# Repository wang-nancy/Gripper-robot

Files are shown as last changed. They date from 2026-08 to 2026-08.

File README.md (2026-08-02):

# 5-Jaw Radial Gripper — FEA (Ansys)

Static structural analysis of a 5-jaw radial gripper with central pushrod
(slider-crank) actuation, in Ansys Mechanical 2026 R1. This is an in-progress
study — preliminary results are reported below with their known limitations, and
the full write-up is in [`FEA-process-documentation.md`](FEA-process-documentation.md).

## The mechanism

Five jaws spaced at 72° are driven by a central pushrod through five crank links:
the pushrod moves axially and each crank rotates its jaw inward (closing) or
outward (opening) — a slider-crank. Roughly 150 mm from mounting flange to jaw tip,
with ~34 mm of pushrod travel between fully open and fully closed.

## Load case & mechanical advantage (from first principles)

No load spec existed, so one was built from the payload. For a 5 kg object held by
friction across 5 jaws, with a 3.0 safety factor and a 0.30 friction coefficient, the
required grip force per jaw is:

```
F_grip = (m · g · SF) / (μ · n)
       = (5 · 9.81 · 3.0) / (0.30 · 5)
       ≈ 98 N per jaw
```

Because the gripper is a slider-crank, the pushrod force needed to hold a given grip
force isn't constant across the stroke. Mechanical advantage is worst at the **fully
open** position, where the crank link sits perpendicular (90°) to the pushrod axis — so
it takes the most pushrod force there to resist a given jaw load. That's the worst-case
actuation point, and the position an actuator-sizing calculation should be run against.

To map this across the full stroke, an interactive linkage force calculator was built
from the linkage geometry (crank ~20 mm pin-to-pin, jaw pivot-to-link-pin ~14 mm, jaw
pivot-to-tip ~38 mm) to estimate mechanical advantage at each position and locate that
worst case. These dimensions are current estimates from a reference model and should be
replaced with exact CAD measurements before the numbers are treated as final.

The FEA itself was run at **50 N per jaw** as an initial test value (below the 98 N
target), applied radially outward at each jaw tip to represent the gripped object
pushing back. Fixed support on the mounting flange.

## Modeling approach & key decisions

- **Transient → Static Structural.** A locked-pushrod grip check has no meaningful
  inertia or time dependence, so the transient formulation was dropped in favor of
  static — faster and better-conditioned.
- **Two-step loading.** Step 1 closes the mechanism through its full stroke with
  forces off; step 2 applies the grip load with the linkage locked closed. Ramping
  displacement and force together (the original single-step setup) let the jaws swing
  open under load before the linkage engaged — the source of the unrealistic early
  deflection. Separating the two fixed it.
- **Convergence handling.** The solver's reference value was dropping near zero, so a
  minimum force-convergence reference of 50 N was set; large deflection kept on for
  the rotating linkage.

## Results (static, two-step)

| Quantity | Value | Notes |
|---|---|---|
| Peak von Mises stress | ~14 MPa | Comfortable margin on steel (yield ~250 MPa). If the peak sits on a sharp edge it's a mesh singularity — fillet + mesh-convergence study needed for a final value, but it doesn't change the conclusion. |
| Total deformation (closing) | ~37 mm | **Rigid-body travel** of the jaws as the mechanism closes — it builds up through step 1 and is flat through step 2, i.e. it's the closing motion, not elastic flex. Roughly matches the pushrod stroke. |
| Deflection under grip load | small (step 1 → step 2 change) | The closed mechanism barely deflects when the 50 N grip load is applied — the deformation curve is flat through step 2. This is the figure that matters for grip accuracy, taken as deformation(t=2) − deformation(t=1). |
| Convergence | Clean | Both load steps converged in 3–4 equilibrium iterations. |

The key reading: "total deformation" for a mechanism conflates the jaws travelling to their
closed position (rigid-body motion through the revolute joints) with the parts actually
flexing under load. Separating the two by load step shows the closing accounts for essentially
all of the 37 mm, and the grip load itself produces only a small elastic deflection — the
mechanism is stiff where it counts.

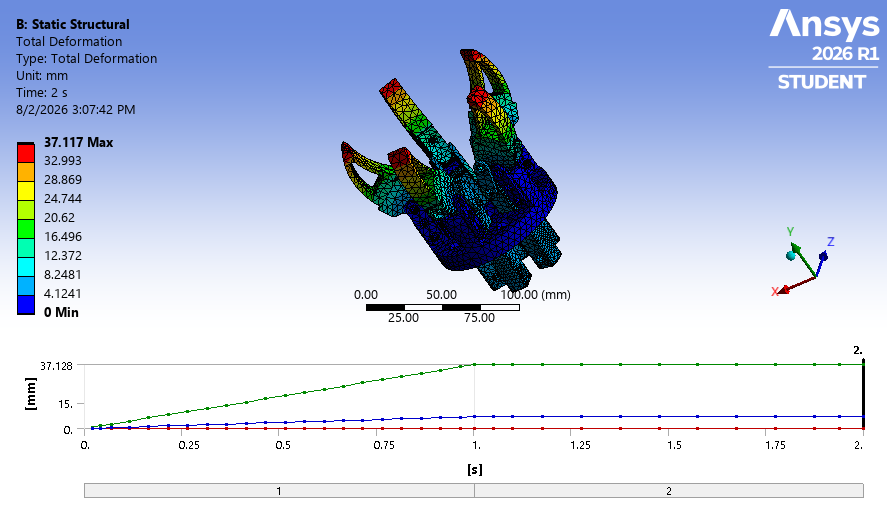
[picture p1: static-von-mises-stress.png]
Equivalent (von Mises) stress


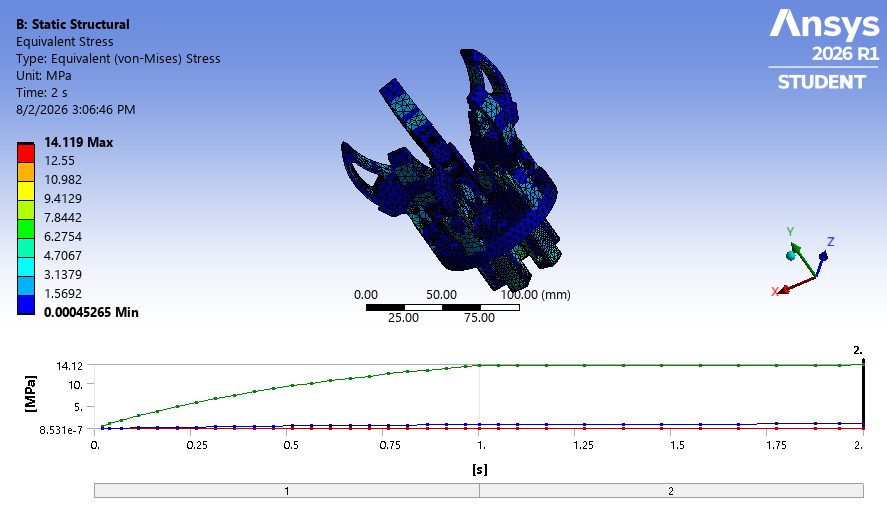
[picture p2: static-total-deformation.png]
Total deformation


## Known issues & outstanding work

- **MPC over-constraint** at the 16 revolute joints: with jaws at 72° there's no common
  rotation axis, so the default MPC revolute joints conflict and cause the convergence
  oscillation above. Results near the pin bores aren't yet trustworthy. **Planned fix:**
  replace the revolute joints with Augmented-Lagrange frictional cylindrical contacts,
  which allow rotation about the pin without needing a shared axis.
- Re-solve with two-step loading and confirm jaw-tip deflection under grip load
  (target < 0.5–1 mm for grip accuracy).
- Refine linkage geometry from exact CAD; fillet the singular edge; mesh-convergence
  study; then fatigue life, pushrod buckling, and pin bearing-stress checks.

## Material

Structural steel — E = 200 GPa, ν = 0.3, ρ = 7850 kg/m³, assigned to all bodies.
With a steel yield around 250 MPa, nominal stresses (away from the sharp-edge
singularity) sit at a comfortable margin; the singular peak still needs a fillet and
mesh-convergence study before it's a usable number.

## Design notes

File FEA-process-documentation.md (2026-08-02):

# FEA Process Documentation, 5-Jaw Radial Gripper

**Software:** Ansys Mechanical 2026 R1 (Workbench)
**Model:** 5-jaw radial gripper with central pushrod actuation
**Analysis of record:** Static Structural, two-step loading

---

## 1. Gripper description

The assembly is a 5-jaw radial gripper built around a central pushrod (slider-crank
actuation):

- **Central pushrod (slider):** moves axially to actuate all 5 jaws simultaneously.
  75 mm long, stroke from 11.69 mm (fully open) to 45.64 mm (fully closed), about
  33.95 mm of linear travel.
- **5 jaw assemblies:** at 72° intervals. Each jaw pivots on a fixed pin in the bracket
  and is driven by a crank link connected to the pushrod.
- **5 crank links:** 20 mm pin-to-pin, converting the pushrod's linear motion into jaw
  rotation.
- **Central bracket:** houses the fixed jaw pivots and the pushrod guide. Ø90 mm base.
- **Mounting flange:** disc with 5× Ø12 mm bolt holes for the robot arm.

The mechanism is a slider-crank: pushrod down closes all five jaws inward, pushrod up
opens them. At the fully open position the crank link is perpendicular (90°) to the
pushrod axis — the lowest mechanical-advantage point in the stroke. Overall size is
roughly 150 mm from mounting flange to jaw tips.

---

## 2. Load case development

No load spec existed, so one was derived from first principles.

**Assumed payload:** 5 kg.

**Required grip force per jaw:**

```
F_grip = (m · g · SF) / (μ · n)
       = (5 · 9.81 · 3.0) / (0.30 · 5)
       ≈ 98 N per jaw
```

where m = 5 kg, g = 9.81 m/s², SF = 3.0, μ = 0.30, n = 5 jaws.

For the FEA, **50 N per jaw** was used as an initial test value, applied as outward
radial forces on the inside face of each jaw tip, the reaction from a gripped object
pushing back against the closed jaws.

**Mechanical advantage.** Because the gripper is a slider-crank, the pushrod force
needed to hold a given grip force varies across the stroke. It is worst at the fully
open position, where the crank link is perpendicular to the pushrod axis, so that is
the position an actuator-sizing calculation should target. An interactive linkage
force calculator was built from the linkage geometry to estimate mechanical advantage
across the stroke and locate this worst case.

Linkage geometry used (estimates from a reference model, to be refined with exact CAD):

- Pivot offset (centerline to fixed jaw pivot): ~18 mm
- Crank link pin-to-pin: 20 mm (measured)
- Jaw pivot to link-pin: 14 mm
- Jaw pivot to tip: 38 mm
- Link-pin angle offset: ~30–40°

---

## 3. FEA model setup

### 3.1 Two analyses: transient (initial), static (adopted)

The model was first built as a **Transient Structural** analysis (standard gravity,
fixed support on the flange, 50 N radial force per jaw tip, a translational joint
driving the pushrod, revolute joints at the pins, large deflection on, weak springs
on, time integration on).

It was then rebuilt as **Static Structural**, and static is the analysis of record.
Both systems still exist in the project, but the static one is the trustworthy result.

**Why static:** a grip check holds the pushrod in a fixed closed position with the
object pushing on the jaws — there is no meaningful acceleration or time-dependent
behavior. Transient solves F = ma at every step, adding inertia effects, longer solves,
and convergence difficulty without adding useful information. (In the transient system,
time-integration effects were in fact turned off, making it a quasi-static solve in a
transient wrapper — another reason to prefer the cleaner static setup. The transient
system also applies closing and grip load in a single load step, which is the setup
that produced the misleading early deflection described in §5.)

### 3.2 Static Structural configuration

| Setting | Value | Reason |
|---|---|---|
| Analysis type | Static Structural | No inertia/time effects needed for a static grip check |
| Large deflection | On | Mechanism undergoes large rotation/translation while closing |
| Weak springs | Off | Weak springs can mask an under-constrained model and inject artificial forces |
| Number of steps | 2 | Separate mechanism closing (step 1) from grip loading (step 2) |
| Gravity | Standard earth gravity | Included |

### 3.3 Two-step loading strategy

**Step 1 — mechanism closing (time 0 → 1):** pushrod joint displacement ramps through
the full stroke; jaw forces held at 0 N. Closes the gripper with no external load.
Substeps: initial 50, min 20, max 200.

**Step 2 — grip load (time 1 → 2):** pushrod displacement holds at the closed position;
jaw forces ramp 0 → 50 N each. Applies the grip reaction with the mechanism locked
closed. Substeps: initial 20, min 10, max 100.

**Why two steps:** the original single-step approach ramped displacement and force
together, so the jaw forces were trying to push the jaws open before the pushrod had
fully closed and the linkage could resist. Separating closing from loading removes that
non-physical transient.

### 3.4 Connections

Current state of the static model:

- **Pushrod:** 1 translational joint (drives the closing displacement).
- **Pins:** 10 revolute joints at the articulating pivots.
- **Non-moving interfaces:** bonded contacts.
- All joints use MPC (multi-point constraint) formulation — the default for Ansys
  revolute joints.

The articulating pivots are still revolute joints (they can rotate), so the mechanism
is free to close; the bonded contacts sit on interfaces that are not meant to move.
The planned upgrade (§4.2) is to replace the MPC pin joints with frictional cylindrical
contacts to remove the residual over-constraint warnings and enable real pin-bore
bearing results.

### 3.5 Material

Structural steel assigned to all bodies: **E = 200 GPa, ν = 0.3, ρ = 7850 kg/m³**.
With a steel yield around 250 MPa, the part is far from stress-limited at this load (see
§5).

---

## 4. Convergence

### 4.1 Current status — clean

The static, two-step model **converges cleanly**. Both load steps solve, each substep
reaching equilibrium in about 3–4 iterations, with displacement residuals several orders
of magnitude below criterion, and the run completes in ~3.5 minutes. This is the behavior
of record.

### 4.2 Earlier oscillation and its cause (resolved)

An earlier configuration showed the force residual oscillating between roughly 0.3 N and
20,000+ N over ~90 cumulative iterations, never settling below criterion — the signature
of contact chatter (contact regions opening and closing each iteration and flipping the
force state). This was tied to the MPC over-constraint condition below. Moving to the
static two-step configuration removed the oscillation.

### 4.3 Residual MPC over-constraint warnings (non-fatal)

The solver still reports MPC/Lagrange over-constraint warnings, because the revolute
joints and several bonded contacts are MPC-based and overlap on shared nodes. In the
current setup these warnings **no longer prevent convergence** — the solve completes
through them — but they are the reason results at or near the pin bores should not yet be
treated as final.

**Root cause:** with 5 jaws at 72°, each pivot pin points in a different direction, so no
single global axis defines the free rotation DOF for all joints, and MPC creates rigid
node couplings that conflict where they overlap.

**Recommended permanent fix (not yet implemented):** replace the revolute pin joints
with **frictional cylindrical contacts using Augmented Lagrange** (pin outer surface as
contact, hole inner surface as target; μ ≈ 0.15 steel-on-steel; symmetric behavior).
Augmented Lagrange uses penalty-based stiffness instead of rigid constraints, and the
cylindrical geometry naturally allows rotation about the pin axis without needing a
defined axis or local coordinate systems — eliminating the MPC conflict and giving real
bearing pressures at each pin-bore interface.

### 4.4 Reference convergence value

An earlier "reference convergence value may be less than the threshold" warning occurred
because the solver's reference force dropped near zero when directional loads were very
small, making tiny residuals look large. It was addressed through the nonlinear force
convergence controls so the reference could not collapse to near-zero.

---

## 5. Results (static, two-step)

Evaluated at time = 2 s (mechanism closed, full 50 N/jaw grip load applied).

| Quantity | Value | Interpretation |
|---|---|---|
| Peak von Mises stress | **14.12 MPa** | Very low for steel (yield ~250 MPa → ~18× margin even taken at face value). If the peak lies on a sharp claw edge it is a mesh singularity and would need a fillet + mesh-convergence study, but it does not change the conclusion. |
| Total deformation | **37.12 mm** | **Dominated by rigid-body closing motion, not elastic flex** — see below. |
| Deflection under grip load | small (step 1 → step 2 change) | The figure that actually matters for grip accuracy; see below. |

### The deformation reading — the key point

For a mechanism, "total deformation" conflates two very different things: the jaws
**travelling** to their closed position (rigid-body motion through the revolute joints)
and the parts actually **flexing** under load. The time history separates them cleanly:

- Total deformation ramps up entirely during **step 1** (closing) and is **flat through
  step 2** (when the grip load is applied).
- If the 37 mm were elastic flex from the grip load, it would grow during step 2 as the
  force ramps on. It does not.

So the 37 mm is the jaw tips moving through space as the gripper closes — approximately
the pushrod stroke — **not** the structure deflecting. The earlier single-step runs that
reported ~23 mm were measuring the same closing travel (made non-physical by loading
before the linkage engaged).

The number that matters for grip accuracy is the **additional** deflection the grip load
causes: deformation(t = 2) − deformation(t = 1). The nearly flat step-2 curve shows this
is small, i.e. the closed mechanism is stiff under the 50 N grip. It should be quantified
by evaluating total deformation at t = 1 and t = 2 (or a deformation probe on a jaw tip
across step 2).

### Trustworthiness

Stress and deflection away from the pin/joint locations (jaw bodies, bracket, flange) are
reliable. Values at or near the revolute-joint locations (pin holes, pivot bores) carry
the MPC caveat of §4.3 and should not drive design decisions until the frictional-contact
model is in place.

---

## 6. Outstanding work

1. **Quantify grip-load deflection** — extract deformation(t = 2) − deformation(t = 1)
   at the jaw tips; confirm it is within the grip-accuracy target (order 0.5–1 mm).
2. **Frictional pin contacts** — replace MPC revolute joints with Augmented-Lagrange
   frictional cylindrical contacts to clear the over-constraint warnings and produce
   trustworthy pin-bore stresses.
3. **Fillet the singular edge + mesh convergence** — add a fillet at the peak-stress
   edge, refine locally, and confirm stress changes < 5% between refinements.
4. **Refine linkage geometry** — replace estimated dimensions in the force calculator
   with exact CAD measurements.
5. **Fatigue analysis** — S-N life estimation at pin holes, lightening holes, and fillets.
6. **Pushrod buckling check** — linear eigenvalue buckling with the peak axial pushrod
   force from the linkage calculator.
7. **Pin bearing stress** — once contacts replace joints, extract contact pressure at
   each pin-bore and compare to bearing strength.

---

## 7. Formulation reference

| Formulation | Method | Over-constraint risk | Status |
|---|---|---|---|
| MPC | Rigid mathematical node coupling | High — caused recurring warnings | Currently used (Ansys revolute-joint default) |
| Lagrange Multiplier | Rigid constraint, different solver | Same as MPC | Evaluated, not recommended |
| Augmented Lagrange | Penalty-based stiffness | No conflict risk | Recommended replacement for pin contacts |
| Pure Penalty | Penalty, less accurate | Low | Not used |

---

## 8. Software and settings summary

| Parameter | Value |
|---|---|
| Software | Ansys Mechanical Enterprise (Workbench) 2026 R1 |
| Analysis type | Static Structural (adopted over Transient) |
| Material | Structural steel, E 200 GPa, ν 0.3, ρ 7850 kg/m³ |
| Units | Metric (mm, kg, N, s) |
| Solver | Direct (sparse) |
| Large deflection | On |
| Weak springs | Off |
| Number of steps | 2 |
| Step 1 substeps | Initial 50, min 20, max 200 |
| Step 2 substeps | Initial 20, min 10, max 100 |
| Mesh | Patch conforming |
| Gravity | Standard earth gravity (on) |
| Connections | 1 translational joint, 10 revolute joints (MPC), bonded contacts on fixed interfaces |
| Convergence | Clean — both load steps; residual non-fatal MPC warnings |

---

*Peak stress 14.12 MPa and total deformation 37.12 mm are from the static two-step run at
t = 2 s. The 37.12 mm is rigid-body closing travel, not elastic deflection (see §5).*

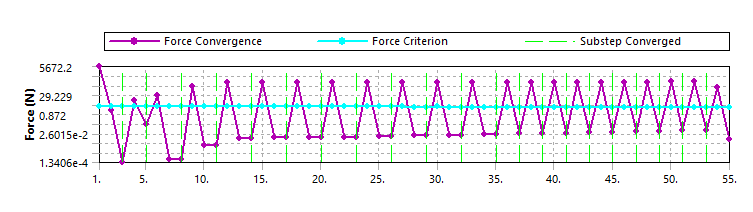
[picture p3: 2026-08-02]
Force-convergence.png

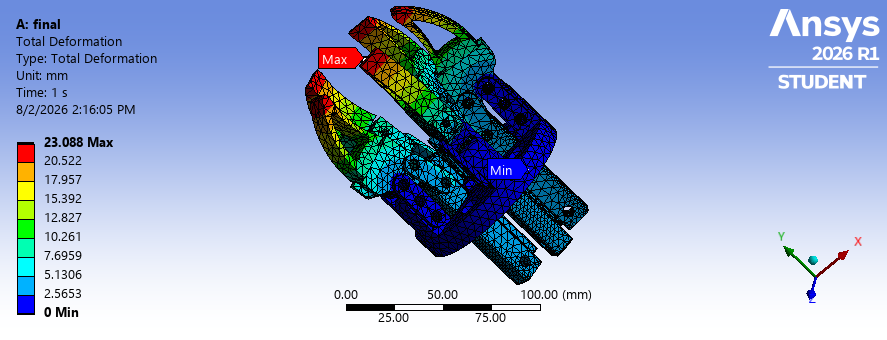
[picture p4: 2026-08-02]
Deformation.png

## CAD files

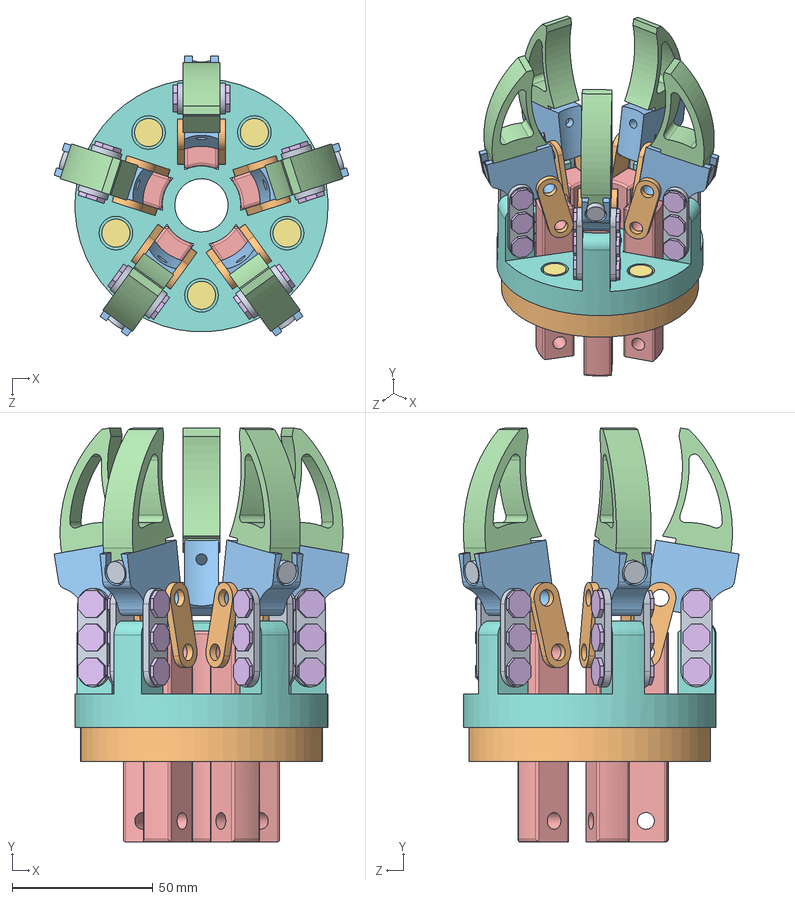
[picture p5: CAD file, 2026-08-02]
cad/finalgripper.SLDASM
104.8 x 147.2 x 99.7 mm

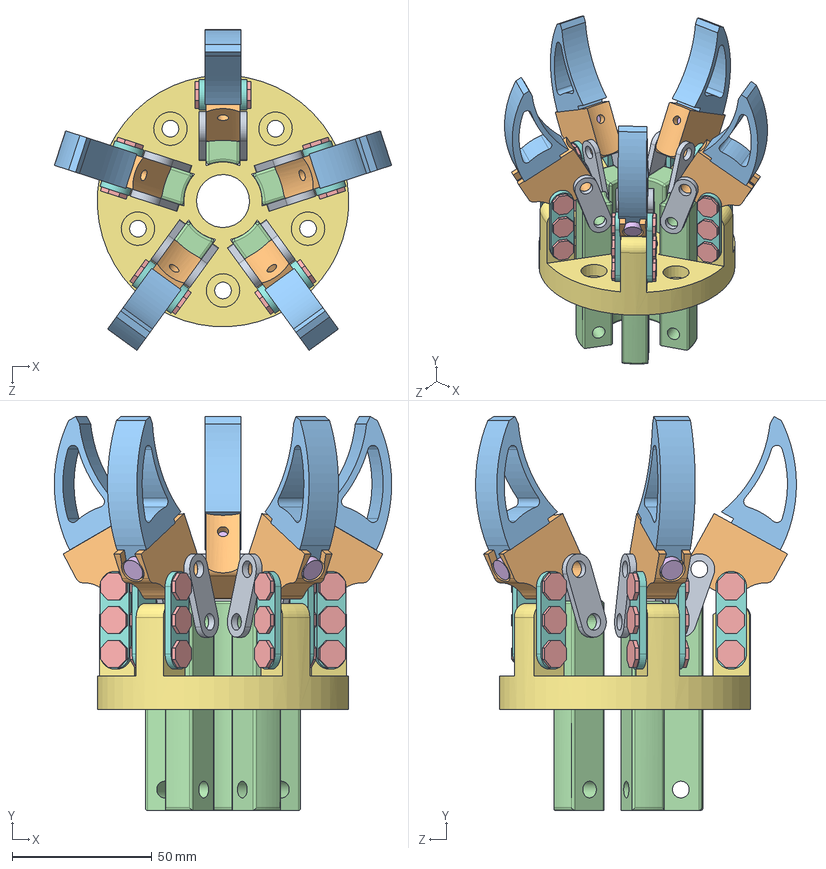
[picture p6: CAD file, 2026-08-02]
cad/simulationuse.SLDASM
120.7 x 141.0 x 114.8 mm

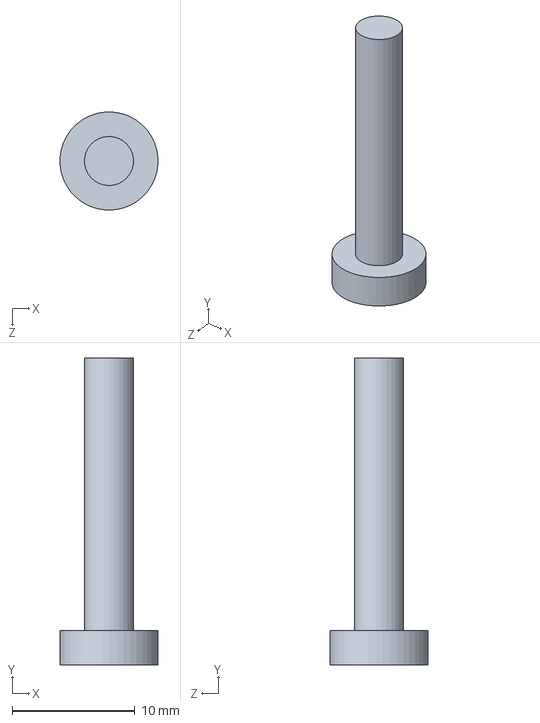
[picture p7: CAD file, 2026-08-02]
cad/Part5.SLDPRT
7.98 x 25.0 x 8.00 mm

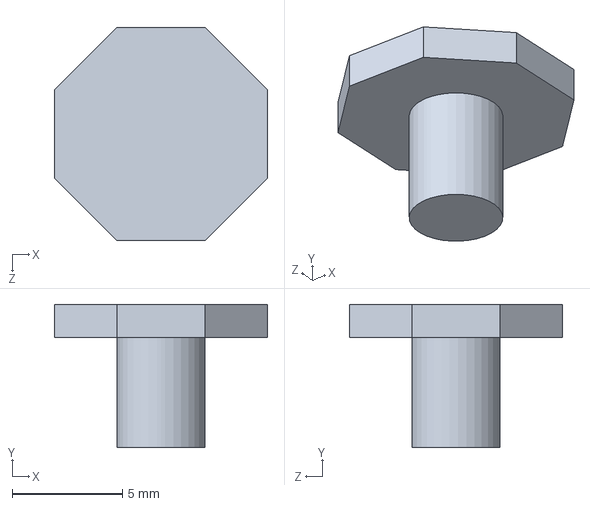
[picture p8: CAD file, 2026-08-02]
cad/Part44.SLDPRT
9.66 x 6.50 x 9.66 mm

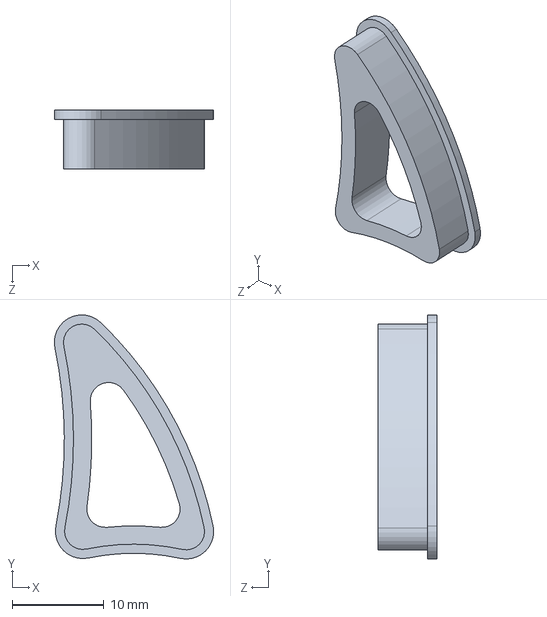
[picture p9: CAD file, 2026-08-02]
cad/11.SLDPRT
17.4 x 26.7 x 6.40 mm

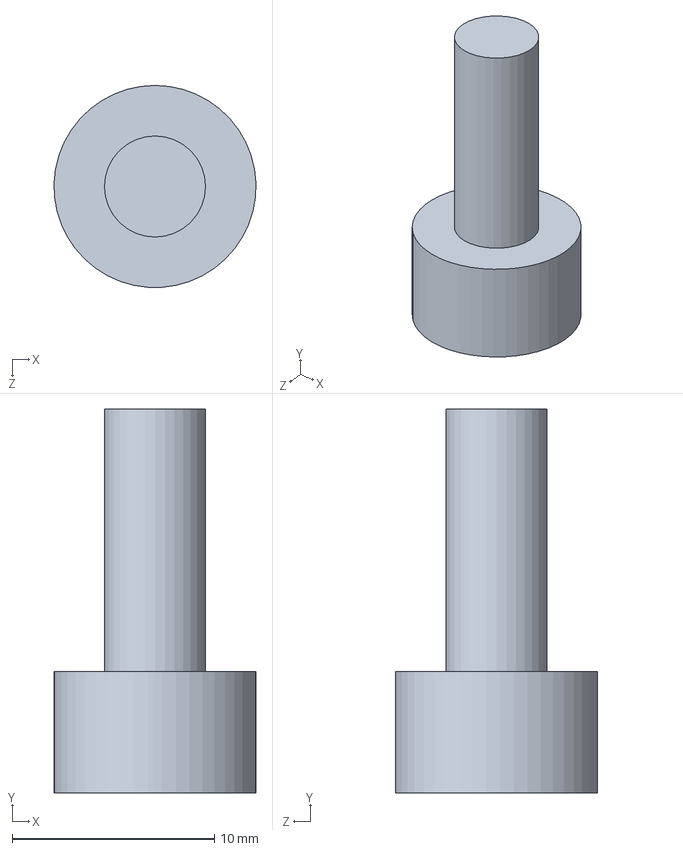
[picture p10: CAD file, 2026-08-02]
cad/Part4.SLDPRT
9.99 x 19.0 x 10.0 mm

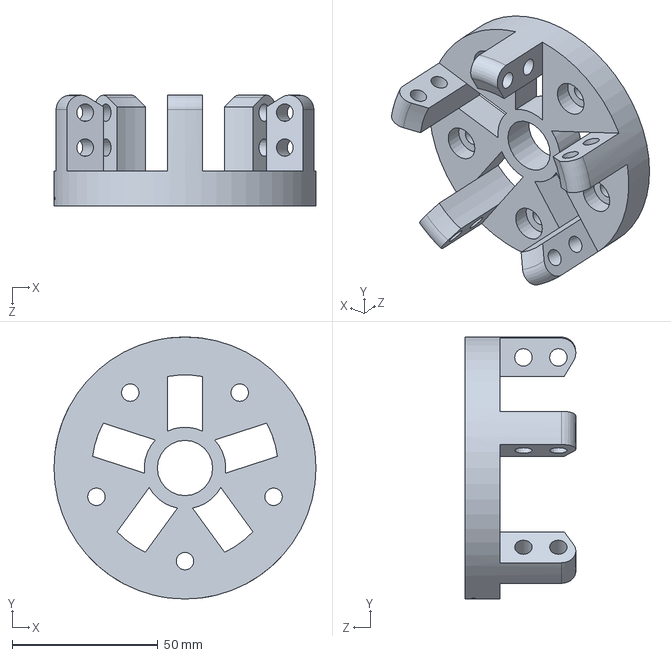
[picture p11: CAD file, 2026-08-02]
cad/part10.SLDPRT
90.0 x 90.0 x 38.0 mm

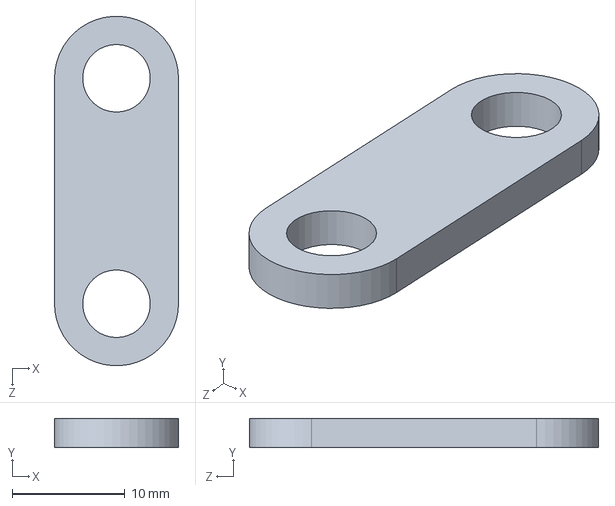
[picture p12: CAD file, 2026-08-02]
cad/Part2.SLDPRT
11.0 x 2.60 x 31.0 mm

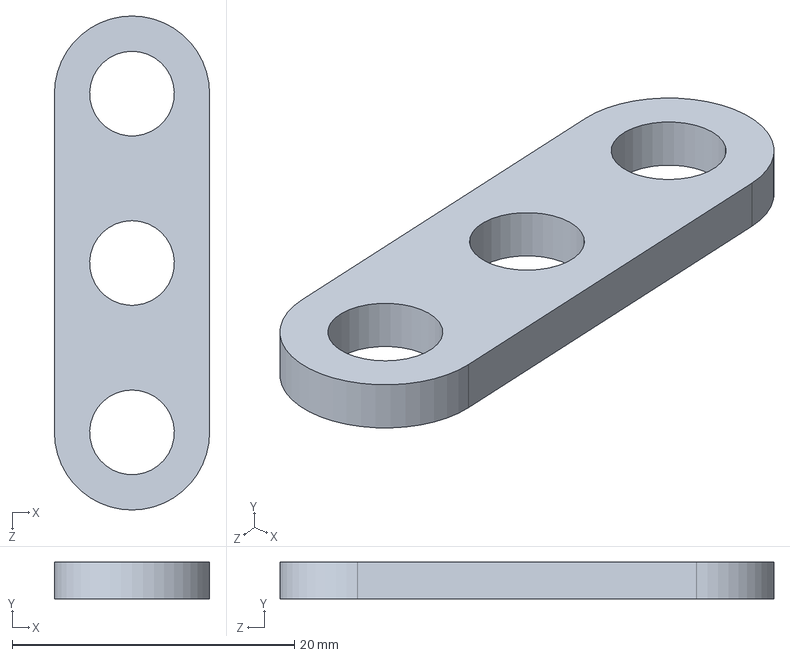
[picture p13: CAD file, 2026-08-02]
cad/Part1.SLDPRT
11.0 x 2.60 x 35.0 mm

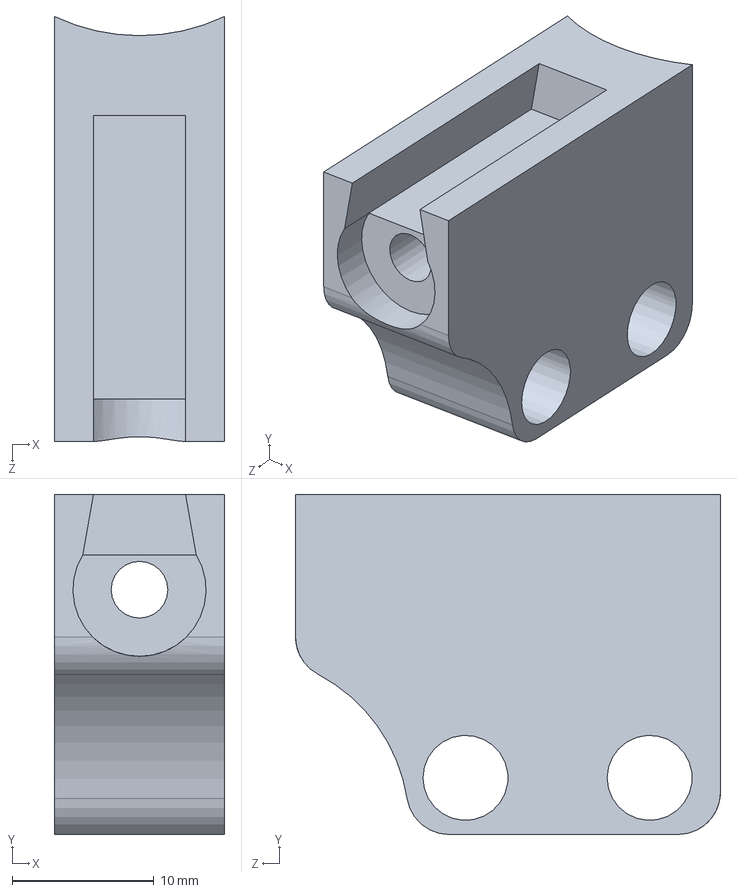
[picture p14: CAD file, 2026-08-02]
cad/part8.SLDPRT
12.0 x 24.0 x 30.0 mm

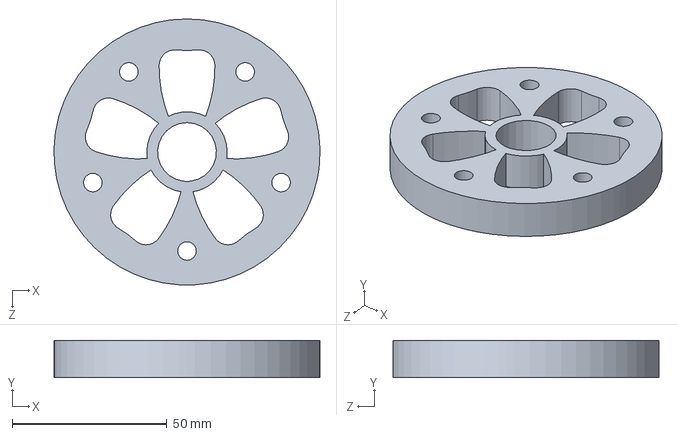
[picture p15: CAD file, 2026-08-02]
cad/part9.SLDPRT
86.0 x 12.0 x 86.0 mm

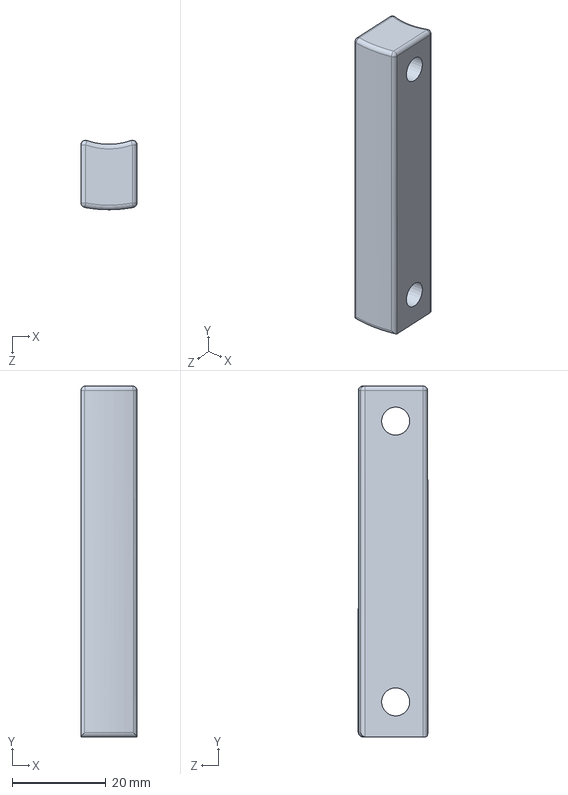
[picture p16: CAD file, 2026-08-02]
cad/part7.SLDPRT
12.0 x 75.0 x 14.9 mm

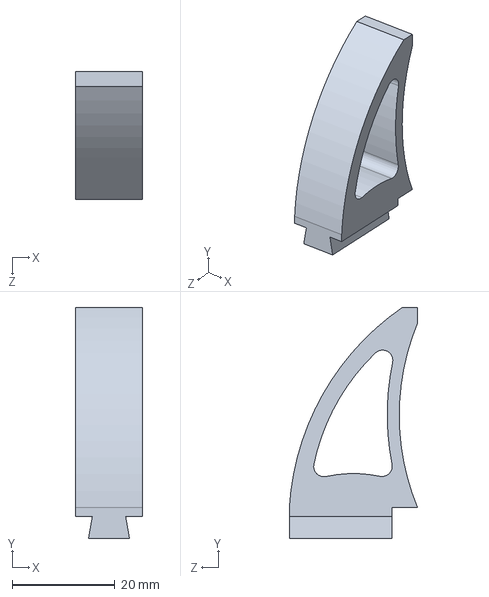
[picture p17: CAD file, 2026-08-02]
cad/6.SLDPRT
13.0 x 45.0 x 25.0 mm
